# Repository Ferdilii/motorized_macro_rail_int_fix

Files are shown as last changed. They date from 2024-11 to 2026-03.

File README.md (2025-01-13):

# Motorized Macro Rail

Macro Video (https://www.youtube.com/watch?v=2CRFKH4DlHQ)

Instructables Link is [here](https://www.instructables.com/DIY-Motorized-Macro-Rail/)

This is a project for a motorized macro focusing rail.  It is used with special
"stacking" software to increase the depth of field of macro images.  This
project is presented as a modification to an existing commercial rail, but could
be extended to use a custom built rail (using steel rods and linear
bearings commonly used in at-home 3D printers and CNC mahines).

## Background

Taking images of very small objects is known as [macro
photography](https://en.wikipedia.org/wiki/Macro_photography).  Using a
[specialized
lens](https://www.bhphotovideo.com/c/product/1399604-REG/venus_optics_ve2528sfe_laowa_25mm_f_2_8_2_5_5x.html),
or an [attachable
modifier](https://www.bhphotovideo.com/c/product/275182-REG/Raynox_DCR_250_DCR_250_2_5x_Super_Macro.html)
makes this type of photography possible.

Due to the [physics of photographic lenses](https://en.wikipedia.org/wiki/Depth_of_field), taking photos of very
small objects typically has a very low depth of field, where only a thin plane
of the object appears in focus, often much less than 1mm.

In general photography, it is possible to "stop down" the aperture to increase
the depth of field.  That is true in macro photography as well, but even stopping
down often does not sufficiently address the depth of field problem.

A modern solution is to take many photos where the focus point is slightly
shifted, then combine these using software.  For example, we would take these
photos:

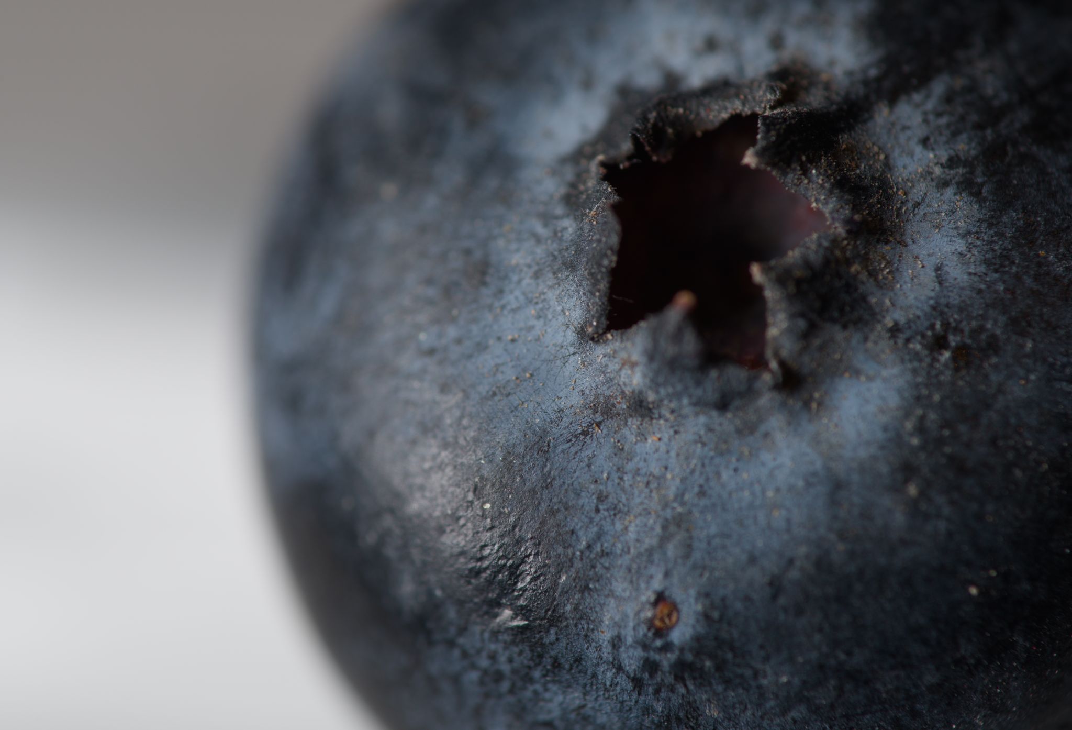
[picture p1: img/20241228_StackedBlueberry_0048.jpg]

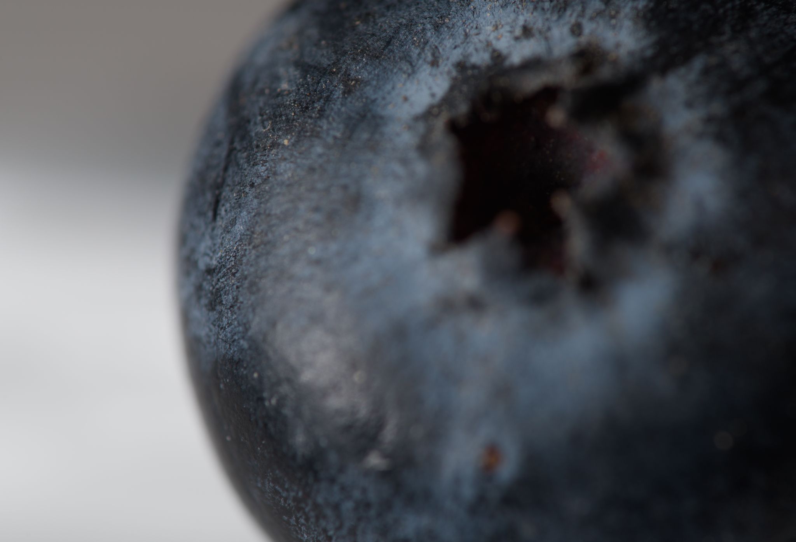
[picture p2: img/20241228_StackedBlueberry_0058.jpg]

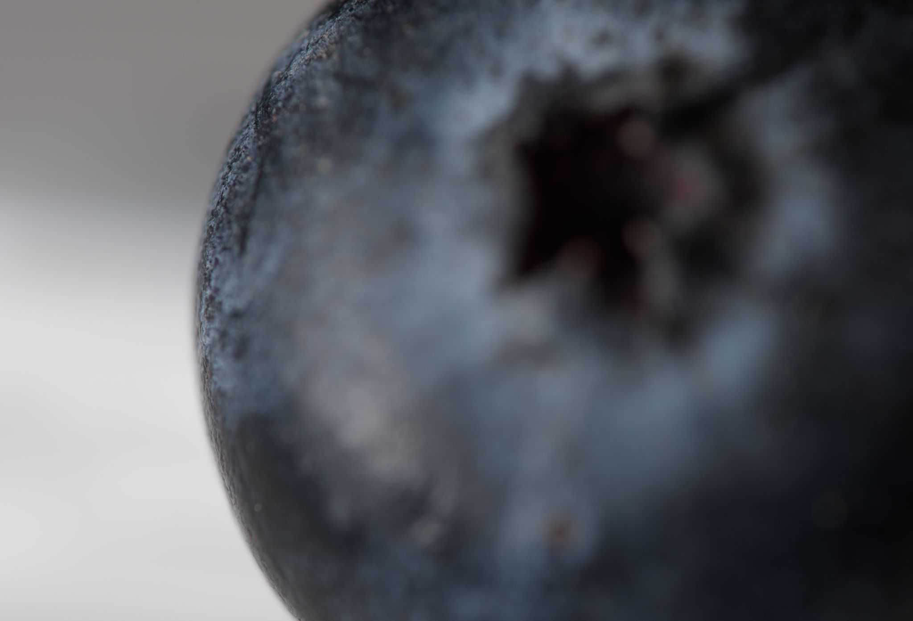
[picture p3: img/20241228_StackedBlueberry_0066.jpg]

(and 29 more)

and combine them into this "stacked" image:

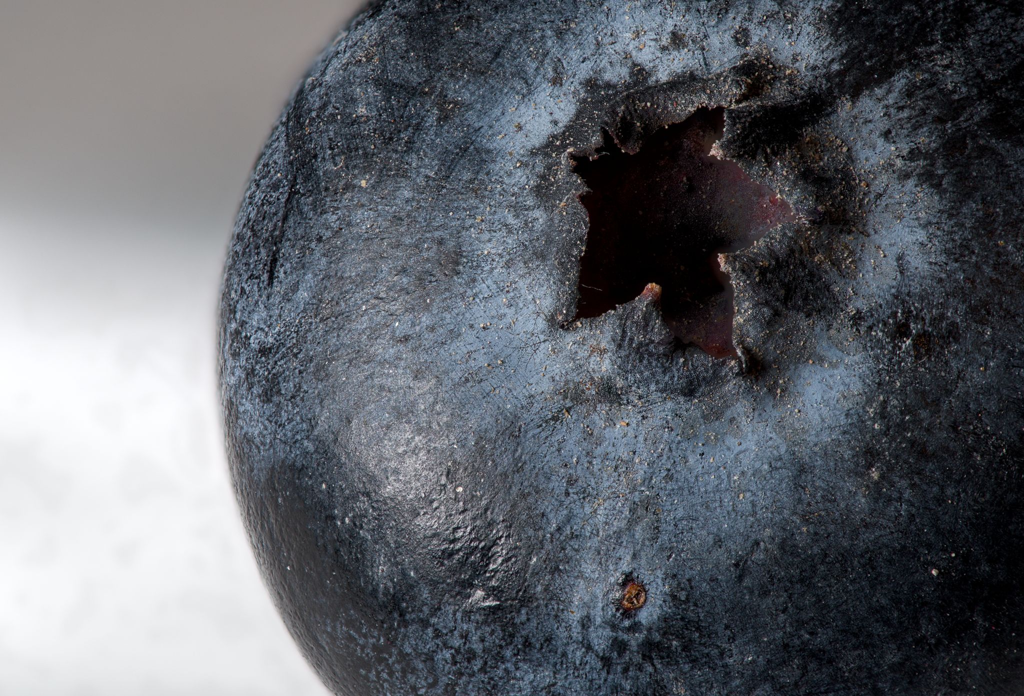
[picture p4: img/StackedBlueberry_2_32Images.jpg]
stacked image


The project here helps to take the captured photos in an automated and
consistent way.

Note that taking these photos requires either a specialized lens, an attachable lens
filter or an extension tube.  There are endless resources on the web on
gettings started.  Here is [one for the basics](https://digital-photography-school.com/macro-photography-for-beginners-part-1/).
Here is one for [extreme macro](https://ferdychristant.com/my-journey-into-extreme-macro-8ddef548e9f3), which is where a rail comes into play.
The amount of detail in this article is impressive and seems beyond what you'll
need to know to start experimenting, but a useful reference as you progress.

## Alternatives

### Manual Approaches

* You can use manual focus on your lens to vary the focus distance. That said,
it can be challenging to get the step size correct and consistent (especially on a
lens not designed primarily for manual focus).  The final stacked image will
thus often have "blurry" areas where there was no in-focus source image to use.
There is also the risk of moving the camera every time you touch it.  Still,
this can be a great way to start and get famiiar with the process.  This method
also does not limit you to small objects as stacking larger scenes can be useful
too.
* You can buy a manual focus rail at many different qualities and price points.
That is the starting point for this project.  The nice thing about these rails
is that they are easy to pack up for field work.  The downside is
that using them manually can feel like tedious work and you risk moving the
camera and introducing vibrations as you interact with the rail.

### Automated approaches

* You can buy commercial rails at different price points.  Here is
[one](https://cognisys-inc.com/stackshot-macro-rail-package.html) and
here is [another](https://www.wemacro.com/US/index.php/product/wemacro-rail-with-power-bank-cable-for-outside/).
Price aside, I think a downside of these solutions is the
interface.  One uses buttons and the other uses a phone app - both seem a bit
cumbersome compared to an analog stick when it comes to positioning the camera.
* [Some cameras](https://fujifilm-x.com/en-gb/learning-centre/using-focus-bracketing-and-stacking/)
have built in [focus stacking](https://en.wikipedia.org/wiki/Focus_stacking)
features while others support remote
control phone/computer [apps](https://camranger.com/camranger-2/) that add the
feature. A limitation here is that you will be limited to autofocus lenses and
[higher-magnification](https://www.bhphotovideo.com/c/product/1712870-REG/venus_optics_ve9028fe_laowa_90mm_f_2_8_2x.html) lenses usually do not offer autofocus as an option.

## Parts List

These are the parts and equipment I used.  Of course, any of them could be
swapped with alternatives with varying degrees of challenge depending on the
part:

### Parts

Prices are what I found in late 2024.  I am mostly suggesting
[Digikey](http://www.digikey.com) here because they let you purchase low part
counts.

* [Stepper motor](https://www.amazon.com/gp/product/B0B93L4H57) ($11) Any Nema 17 motor designed
for 3D printers will work well.  I'm using a lower power pancake style motor, which is still
sufficient for the job (as the leverage on a macro rail knob is very high)
* [Raspberry PI Pico](https://www.digikey.com/en/products/detail/raspberry-pi/SC0915/13624793) ($4).  You could
opt for the [unit with Wifi/Bluetooth](https://www.digikey.com/en/products/detail/raspberry-pi/SC0918/16608263)
if you want to try and trigger your camera wirelessly but note that this
enhancement will require firmware changes and could be a challenge.
* [128x128 OLED](https://www.amazon.com/dp/B0CFF435XZ) ($12).  The UI is 
designed for this resolution using a 8x16 font.  With some firmware changes, you
could go with a 128x64 and switch to an 8x8 font.  See
[src/firmware/README.md](src/firmware/README.md) for more details.
* [4 push-buttons](https://www.digikey.com/en/products/detail/schurter-inc/1301-9314-24/8536705) ($1).
* [Joystick](https://betafpv.com/products/literadio-transmitter-nano-gimbal-for-literadio-3-and-2-se?variant=39628763529350) ($6).
I'm using an RC gimbal (pitch-roll type) which gives a feeling of precise control.  You
an get these new or salvage one from an old RC radio.  Alternatively,
you can opt for a commonly-available ["PS2 stick"](https://www.amazon.com/HiLetgo-Controller-JoyStick-Breakout-Arduino/dp/B00P7QBGD2)
that will be less precise but possibly good-enough.
* [Voltage Regulator](https://www.digikey.com/en/products/detail/texas-instruments/LM7805CT-NOPB/3901929) ($2) most stepper
motors need a minimum of 12V, which is beyond what the PI Pico onboard regulator
can accept as input, thus you'll need a regulator to help it out.  I went with the famous
[LM7805](https://www.digikey.com/en/products/detail/texas-instruments/LM7805CT-NOPB/3901929) which will be powering the Pico
and OLED.  Anything between 3.3V and 5V which can deliver > 200 mA should be well
into the sufficiency range.
* [A4988 Stepper Motor Driver](https://www.amazon.com/HiLetgo-Stepstick-Stepper-Printer-Compatible/dp/B07BND65C8) ($2).
A Pico microcontroller is not designed to power a motor directly and you will need
power electronics.  The [A4988](https://www.pololu.com/file/0j450/a4988_dmos_microstepping_driver_with_translator.pdf)
gives you both the power and an easy-to-use interface which make the motor run smooth and quiet (using microstepping) and provides a number of protections (such as overcurrent protection).
* [Power connector](https://www.amazon.com/dp/B09128LHGG) ($2).
I'm going with a XT-60 connector used with RC LIPO batteries but it's really up to you.  The design will
support between 12V and around 30V but you'll want to double check the limits
of your chosen motor and voltage regulators.
* [Camera remote shutter release](https://www.digikey.com/en/products/detail/same-sky-formerly-cui-devices/SJ1-2503A/738680) ($1).  I went with
a 2.5mm jack for this but since it's the not the camera side, your options
are flexible.  Many cameras support a simple electronic shutter release.  If yours
doesn't, you can probably improvise something or go with the manual shutter
release option the firmware provides (more on that later).
* [4N25 Optocoupler](https://www.digikey.com/en/products/detail/liteon/4N25/385762) (< $1)
This is used to trigger the camera.  An [optocoupler](https://en.wikipedia.org/wiki/Opto-isolator) triggers the camera using light,
meaning that the electrical system of the camera and focus rail are fully isolated.  This electrical
isolation can bring some peace-of-mind about connecting your camera.
* [100 Ohm resistor](https://www.digikey.com/en/products/detail/vishay-dale/RLR07C1000GSB14/3141196) (<$1)
The optocoupler needs one of these.
* [470 uF capacitor](https://www.digikey.com/en/products/detail/rubycon/6-3YXJ470M6-3X11/3134408) (<$1)
The a4988 motor driver requests one of these on the motor voltage input to smooth
out voltage transisents that are common with powering motors.
* [2x 10 uF capacitor](https://www.digikey.com/en/products/detail/tdk-corporation/FK28X5R0J106MR000/2815522) (<$1) These help smooth the 5V power supply.

You will also need a rail.  I went with the [NM-200s](https://www.amazon.com/dp/B0BXKFGLF3?th=1)
which I acquired on sale for $150.  I'd say the [NM-180s](https://www.amazon.com/dp/B08BCCFQC3)
is likely as good for $130 retail.  There are also a number of cheaper options that I have no
direct experience with, such as [this one for $89](https://www.amazon.com/Adjustment-Photography-360%C2%B0Rotating-Compatibility-MS18/dp/B0C89CLJ8N).  If you go with a NM-XX0s rail as I used, you can use the provided `.STL` files directly.  For other rails
you will need to resize the adapter using the free OpenSCAD and instructions provided later
in this document.

### Equipment

* 3D printer.  This is used to create the motor-to-rail interface and
the housing for the electronics.  There are many techniques with wood working,
metalworking, [CNC](https://www.sainsmart.com/products/sainsmart-genmitsu-cnc-router-3018-pro-diy-kit),
etc, that could be alternatively used if you have the needed skills and equipment.
* Camera gear.  More on that in the process walkthrough later.  In short, just about
any camera with interchangeable lenses can be used. 

## Electronics Build

Here is the schematic.

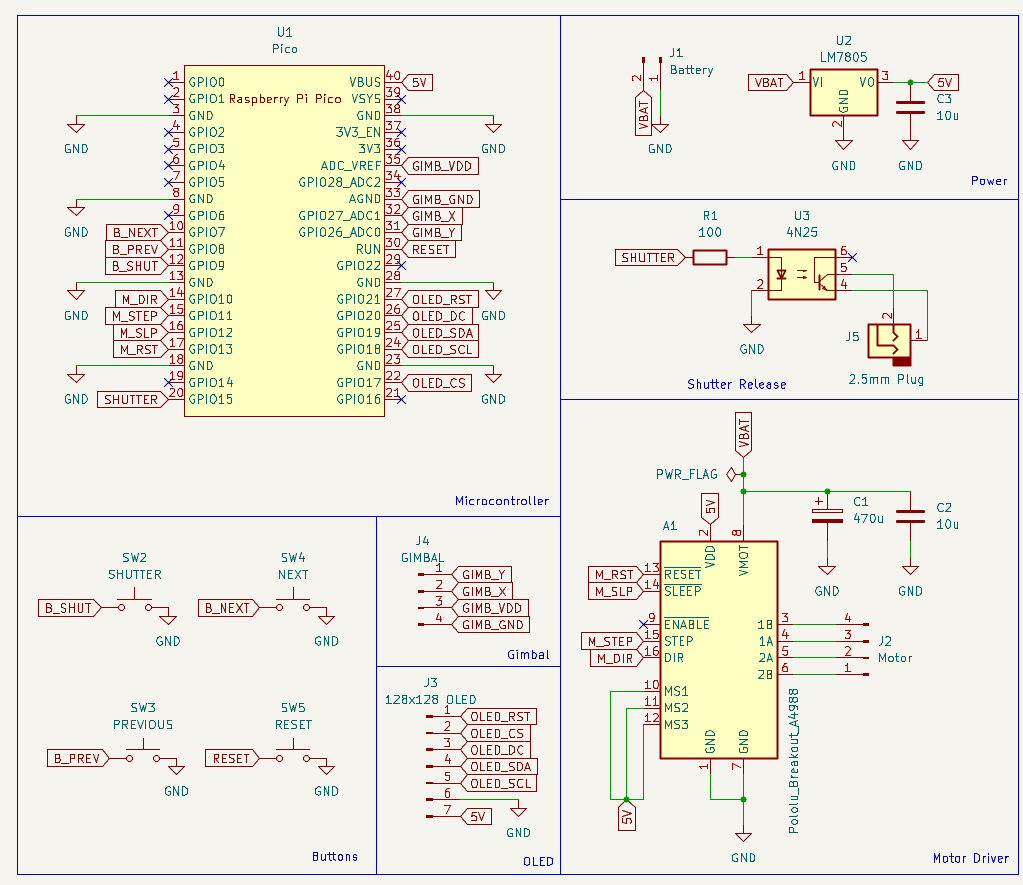
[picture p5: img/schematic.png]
schematic


There are around 2 dozen connections to be made here which makes most
assembly methods possible.  Here is the whole thing implemented on
a breadboard:

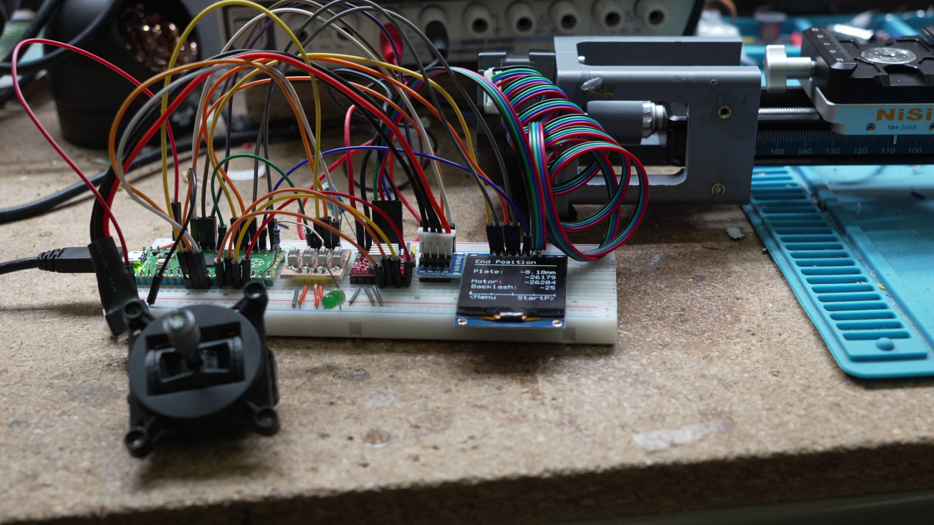
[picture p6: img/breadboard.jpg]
breadboard


You could transfer the electronics to a [perf board]() and be done
with this step.  

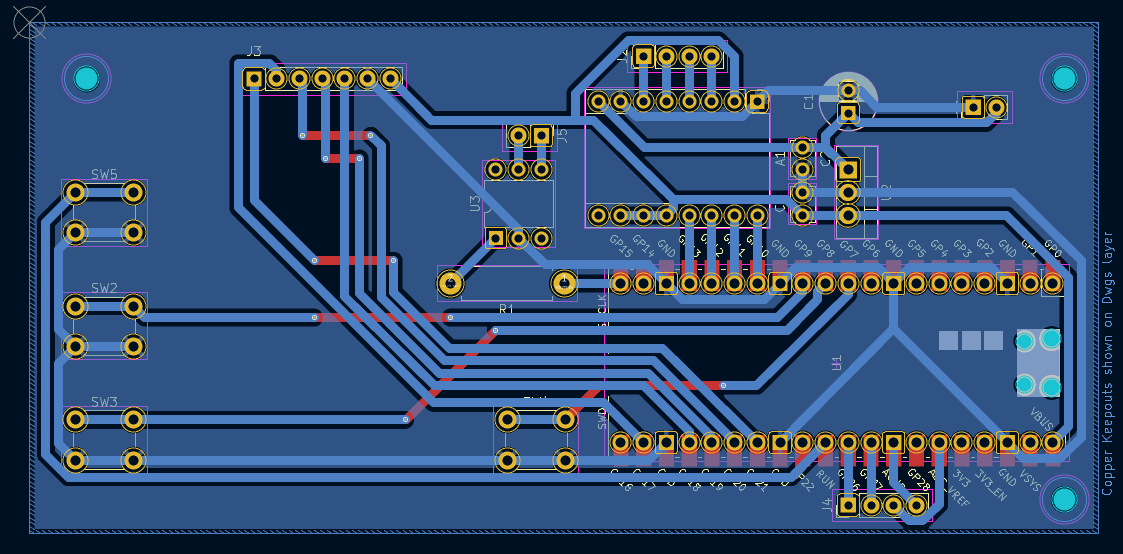
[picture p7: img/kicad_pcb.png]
pcb layout


Since I have a 3018 CNC machine, I decided to go a little farther and cut out a PCB:

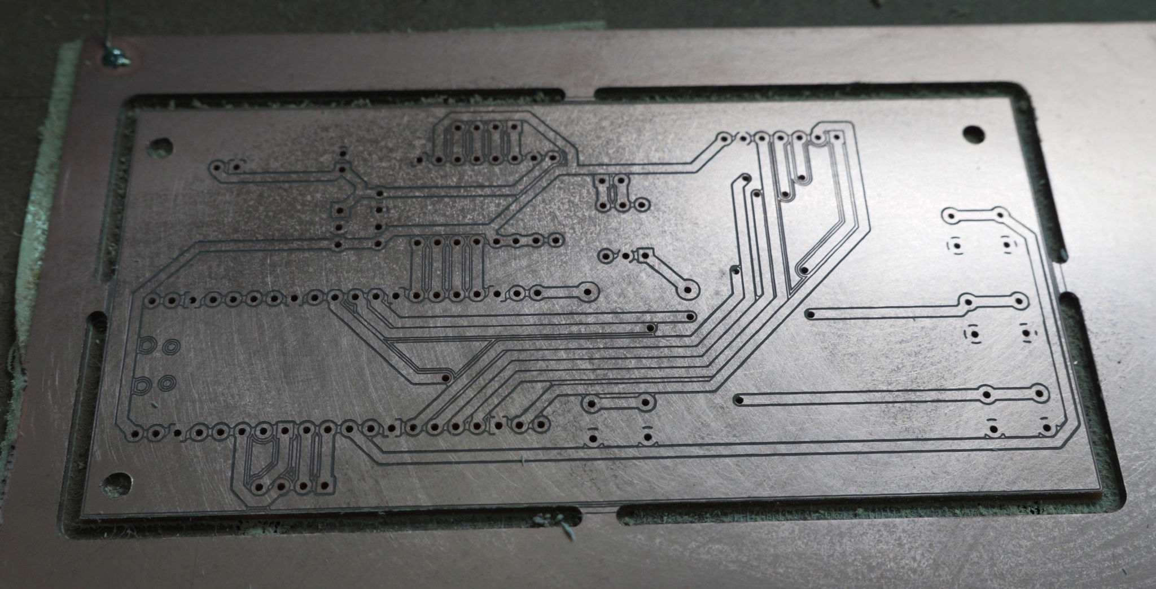
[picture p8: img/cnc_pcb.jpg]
cnc photo


Here is the board flipped over and populated with components:

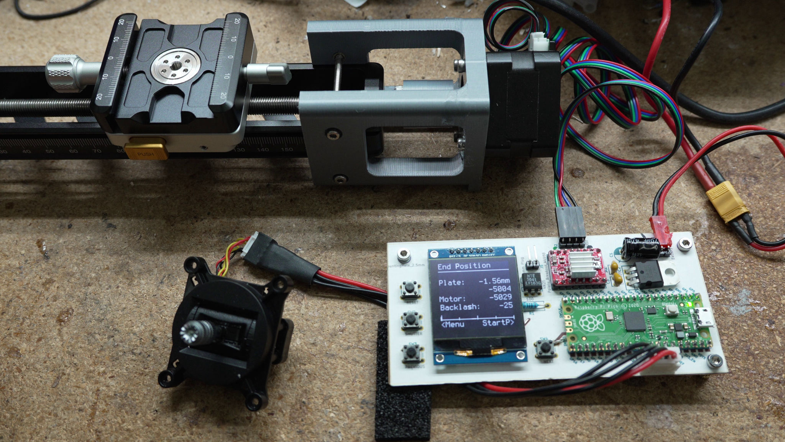
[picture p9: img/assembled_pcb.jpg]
finished board


If you want to use a CNC, chemical etch, or order a manufactured board,
you can find the needed files in the [`motor_rail_kicad/`](motor_rail_kicad) directory.

## Code Build

Here you have the "easy" option of uploading a precompiled `.uf2` file to your
Pico or the "flexible" option of building the binary yourself.  Both options are
free.

### Precompiled

There are many guides for how to do this, just a Google search away. Here is my
version.

* While holding down the `BOOTSEL` button, plug in the Pico via USB
* It should mount as a USB drive
* Copy the [`firmware/macro_rail_automater.uf2`](firmware/macro_rail_automater.uf2) file to the USB drive
* Unplug and replug the Pico

There are alternatives you can explore as well:

* There is a [`picotool`](https://github.com/raspberrypi/picotool) program which
allows you to load the `macro_rail_automater.uf2` file directly.  I prefer it.
* [Pin 30 on the Pico](https://www.raspberrypi.com/documentation/microcontrollers/pico-series.html#pinout-and-design-files) is named `RUN`.  If you drive it to 0V, it will reset the PICO.
If you do this while holding `BOOTSEL`, you can upload firmware which is
ergonomically easier and with less USB port wear-and-tear.  I
put a switch between `RUN` and ground (battery negative) whenever I go with a
Pico for this reason (as is done in the schematic above).

### Build firmware yourself

To start, you'll need a working development environment.  I'll point you to the
[official docs](https://datasheets.raspberrypi.com/pico/getting-started-with-pico.pdf) if you are not there yet.  I personally prefer following Appendix C "Manually configure your environment" first over the VS Code docs, then add VS Code later so I have both options available.

Once your blinking light project is working, you are nearly done.  Here
are the command line instructions (use the official Pico docs as a guide for VS Code)

* First, go into the [`src/`](src) directory.
* In Linux, type [`./bootstrap.sh`](src/bootstrap.sh).  In Windows, you'll need to follow
the steps listed in `./bootstrap.sh` which are identical to the official
docs.
* `cd build`
* `make`

At this point, you'll hopefully have your own `macro_rail_automater.uf2` file that you can load
on the your Pico.

## Macro Rail Physical Interface

The goal is to interface the stepper motor with the macro rail of your
choosing.  I ended up going with the [NM-200s](https://www.amazon.com/dp/B0BXKFGLF3)
focusing rail which I find sufficient but not amazing.  It has some flex which
leads to some shifts between photos but the stacking software compensates for this.
I *might* try a cheaper one or potentially DIY one with some steel rods and
linear bearings, if I find the time/motivation.

For the route I took, only two printed parts are needed.  One interfaces
the rail to the motor using a clamping interface:

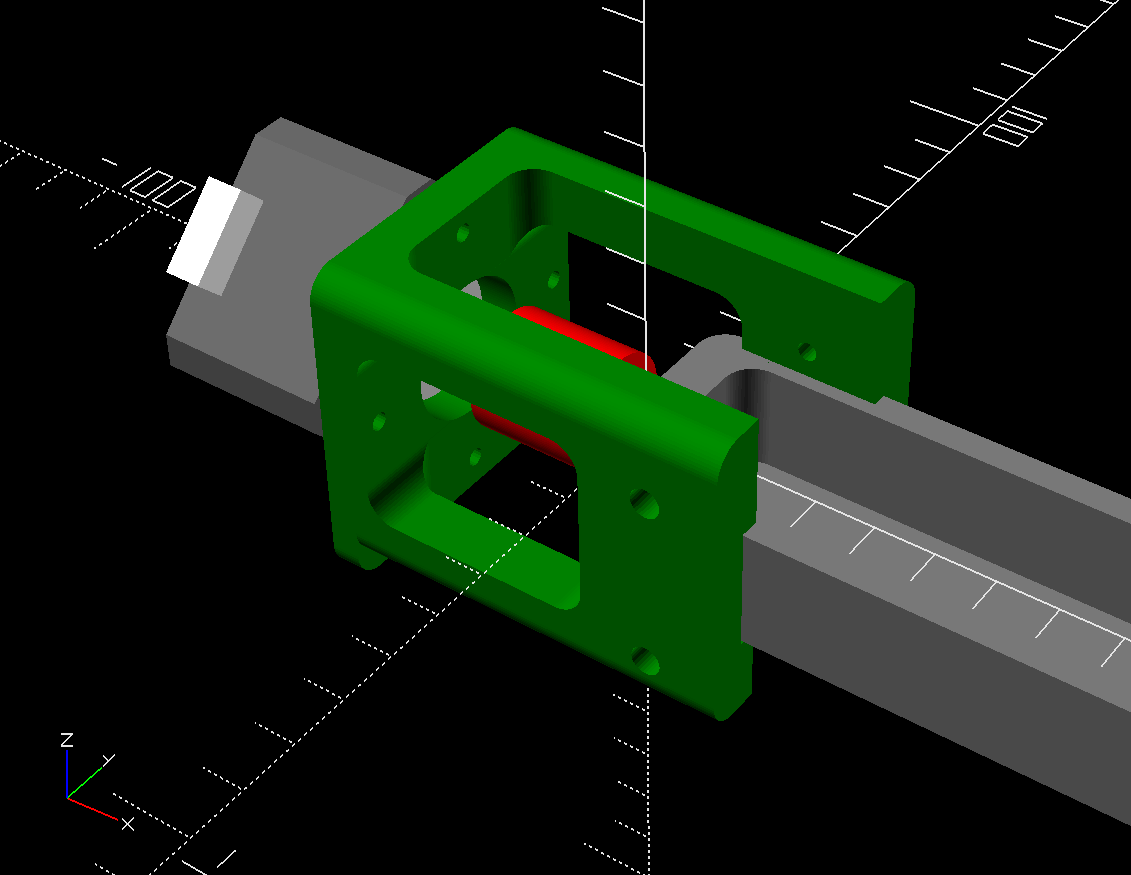
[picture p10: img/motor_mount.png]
clamp interface


The other printed part interfaces the motor shaft to the finger adjustment
knob:

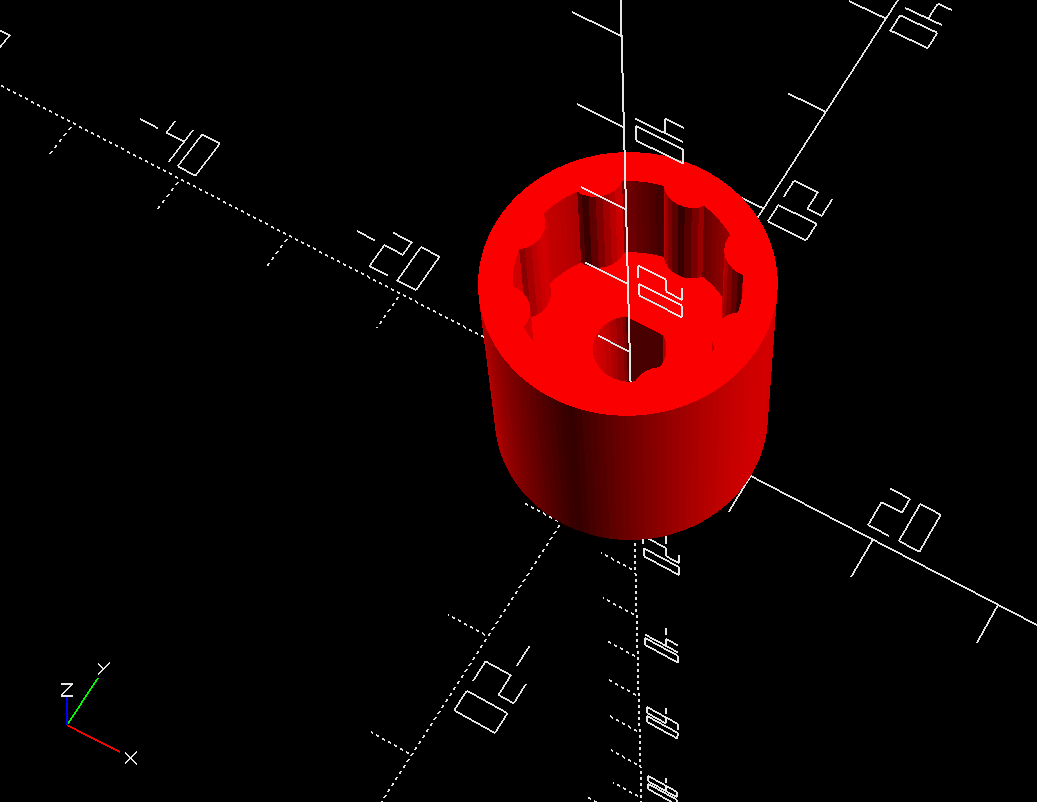
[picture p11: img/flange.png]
shaft interface


I have included rendered `.stl` files in the [3d_models/stl](3d_models/stl)
directory that you make be able to use directly if you have a compatible rail.

If you do not have a a matching rail, you can probably make a few tweaks to the
model and have a working result.  By using the freely-available [OpenSCAD](https://openscad.org/), you can adapt
the clamp interface to various different rails by editing
[`motor_mount/focus_rail.scad`](3d_models/motor_mount/focus_rail.scad) and changing
the following parameters to match your rail:

```
RAIL_BODY_WIDTH = 37.8;
RAIL_BODY_HEIGHT = 20;
```

The numbers above (in mm) are for the [NM-200s](https://www.amazon.com/dp/B0BXKFGLF3).

The knob interface design should be adaptable to most (but not all) rail
designs.  The file to change is [`motor_mount/knob.scad`](3d_models/motor_mount/knob.scad)
with the following variables likely being relevant:

```
KNOB_DIAMETER = 15.1;
KNOB_INSET_DIAMETER = 13.2;
...
finger_cutout_diameter = 4;
finger_cutout_count = 8;
```

## Motor Current Calibration

You will need to calibrate your A4988 driver board to set the current properly
for your chosen stepper motor.  Intructions on how to calibrate are
[here](https://www.pololu.com/product/1182) with alternate instructions
[here](https://ardufocus.com/howto/a4988-motor-current-tuning/).

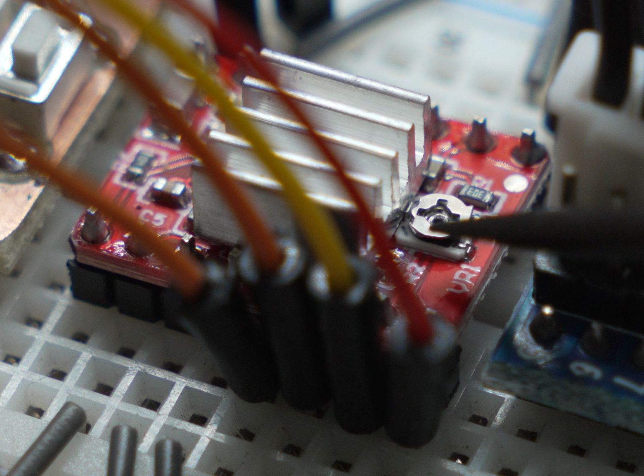
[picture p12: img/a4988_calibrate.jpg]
motor calibrate


## Firmware Settings

If you power on the unit and press the "previous button", you are taken to
a menu that lets you chang the following settings:

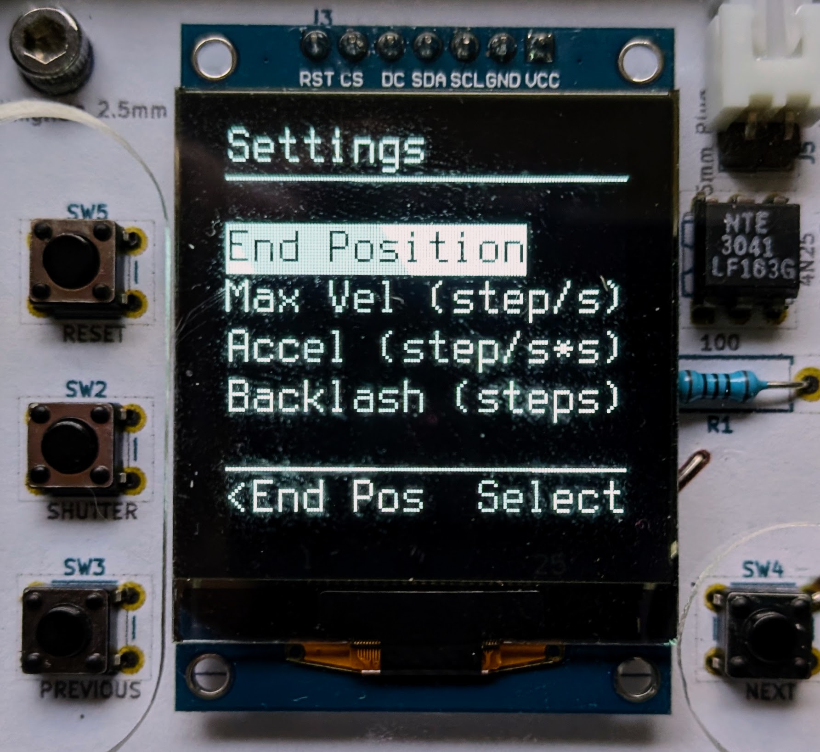
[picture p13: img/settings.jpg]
settings


* Max Velocity: The maximum motor turn speed.  Too high of a value may cause the
stepper motor to miss steps or lead to long spin down times if acceleration
is not risen to match.
* Acceletaion: The maximum motor acceleration/decelleration.  Too high of a
a value may cause the motor to miss steps or lead to rail vibrations.
* Backlash: When the motor switches direction, it will take some slack before
the main gear is engaged, this is known as backlash.  If you want a perfect
value, you can run the test mode with a caliper attached to the rail.
It's usually not critical that this number be fully tuned.
* Settle Seconds: This is how long the controller should wait between
stopping the rail and taking a photo.  The intent is to allow any
vibrations/oscillations from rail decelleration to subside.  You
can also use this value to give your camera more time to write to
its memory card.

### Steps / mm

This final menu item relates to both your motors steps/rotation and
your rails rotations/mm.  The a4988 driver is configured in the schematic
above to 16x microstep mode, meaning that 16 steps equal one step on the motor.
The formula to use is thus:

```
  motor_steps_per_rotation * 16 / mm_per_rotation
```

For my case,
I'm personally using a
[200 steps/rotation stepper motor](https://www.amazon.com/gp/product/B0B93L4H57) and a 
[1 rotation/mm rail](https://www.amazon.com/dp/B0BXKFGLF3),
thus my number will be 200 * 16 / 1 = 3200.

## Controller Case

In the folder [3d_models/controller](3d_models/controller/), there is a file named [controller.scad](3d_models/controller/controller.scad), which OpenSCAD will render like this:

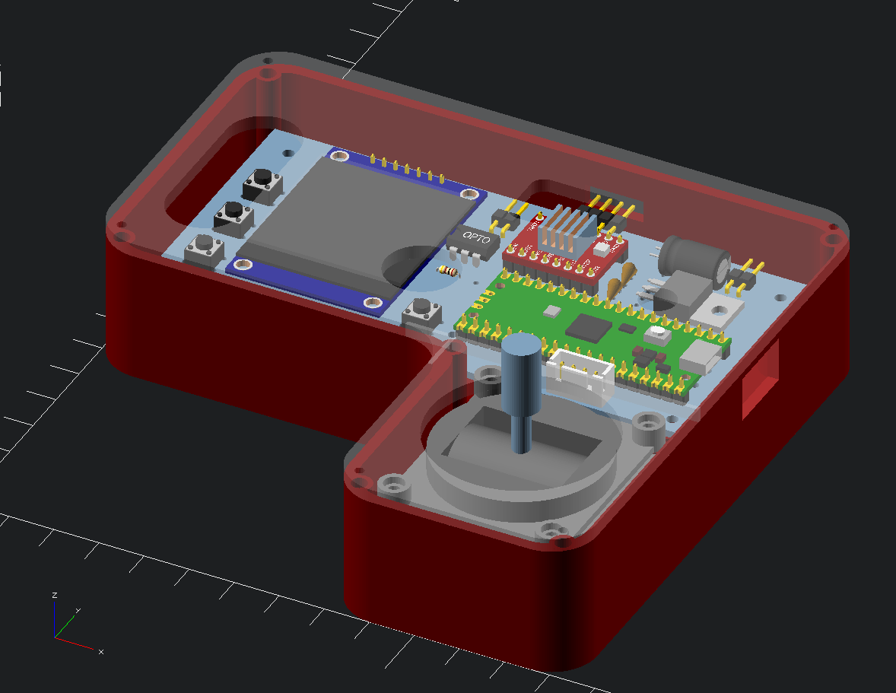
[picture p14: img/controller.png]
controller image


This model is intended for the parts and PCB model that I'm using.  If you went
with different parts, made a differently-shaped PCB, or do not have a CNC
machine for the acrylic cover, you can either try to modify the given design or
make a custom one using whatever parts / methods work for you.

If you want to start with an STL file, you can find one at [3d_models/stl/controller.stl](3d_models/stl/controller.stl)

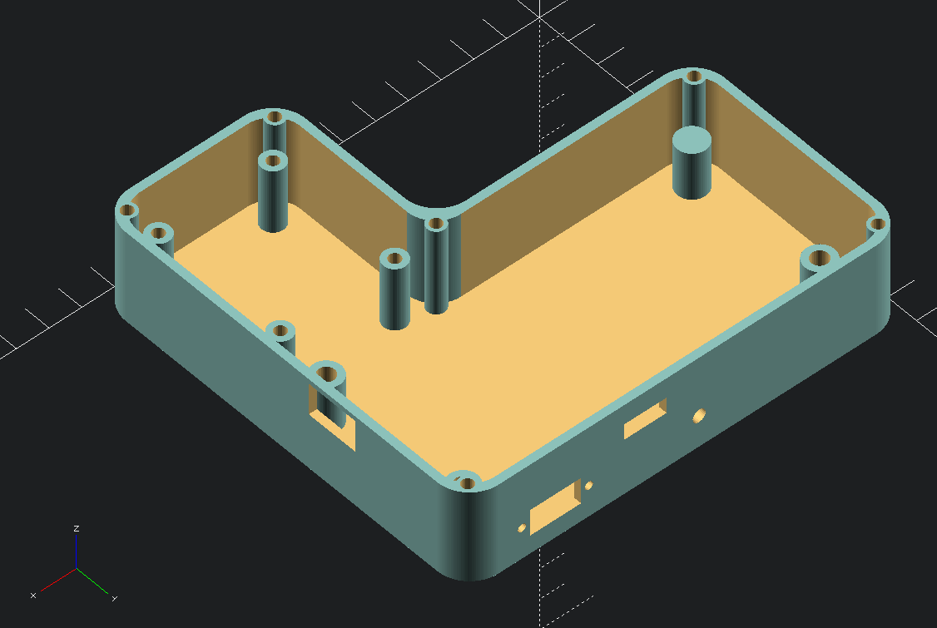
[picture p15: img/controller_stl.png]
controller stl


If you want to edit the OpenSCAD model directly, it can be found at
[3d_models/controller/controller.scad](3d_models/controller/controller.scad).
The model is parametric and has many varialbes you can change and experiement
with.  The bottom of the file allows you to turn components on and off using th the usual OpenSCAD prefixes of `*`, `!` and `//`:

```
// comment out everything but controller for the 3d print model
controller(false);
placed_pcb();
placed_gimbal(); 
cover();
// comment out everything but this to create a dxf projection
//cover_projection();
```

The `cover_projection()` can be used to create a `.dxf` export for CNC or a laser cut.
Alterrnatively, you can 3D print the cover, likely with some modifications
to allow the screen to be viewed:

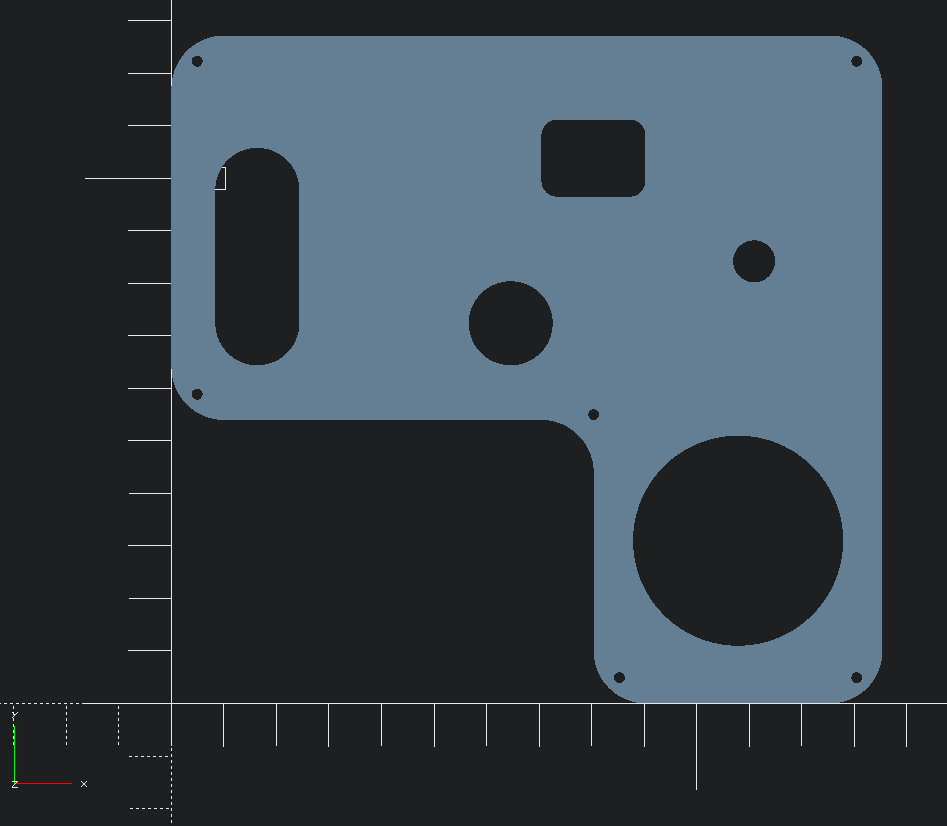
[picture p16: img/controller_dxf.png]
controller dxf


An exported DXF is available at [3d_models/dxf/controller_cover.dxf](3d_models/dxf/controller_cover.dxf) if you would like to use that as your starting point.

## Process Walkthrough

This section talks about the end-to-end experience of using the rail.

### Setup

You first need to attach the stepper motor to the rail by sliding it on and
*gently* tightening the bolts (don't overdo it).  The motor can easily be
detached if you don't need it for a given session.`

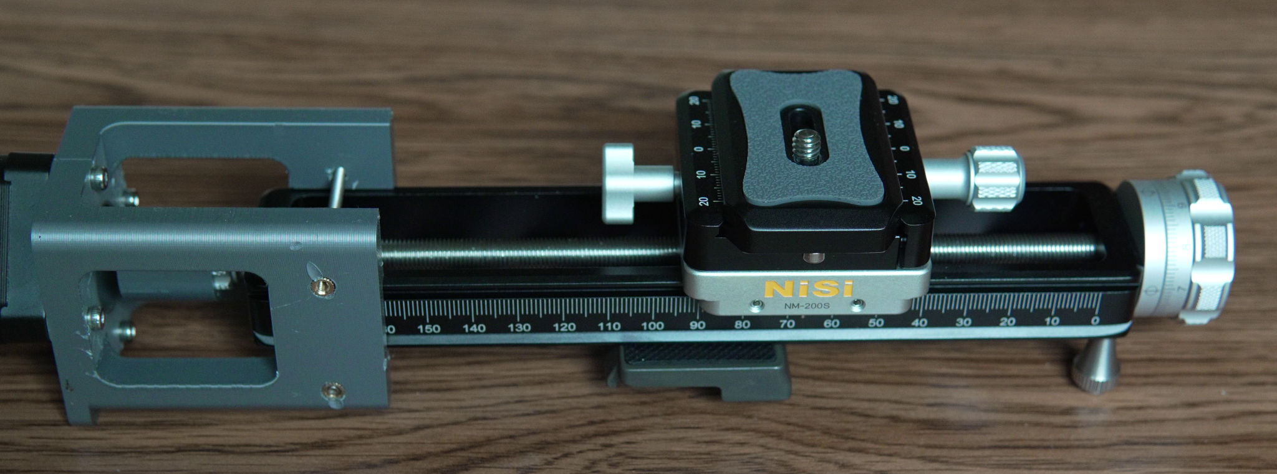
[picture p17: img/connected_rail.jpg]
attach rail


Next line up the camera and target and make sure that nothing is moving.

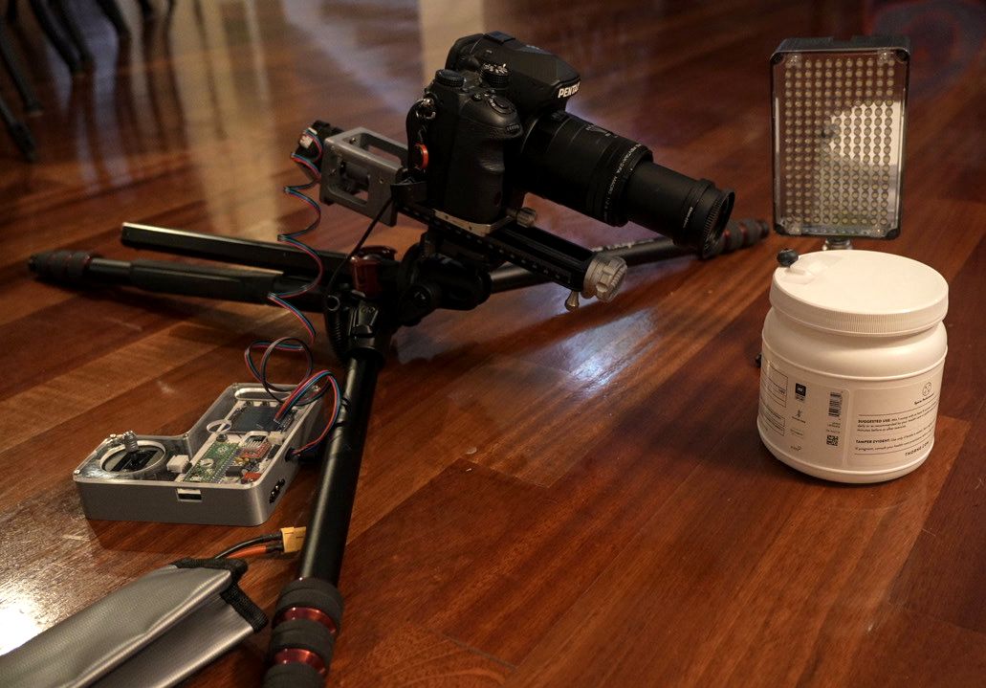
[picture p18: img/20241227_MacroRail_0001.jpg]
camera setup


It's good to have a light on your subject to reduce to exposure time and make
the light consistent.  Where you place the light is an artistic choice but side
lighting is a good starting point.  Flash is an option but you might need to
slow down your process to allow the flash to charge between shots.

You'll want manual everything on your camera, focus, shutter speed, aperture,
ISO and white balance.  If these parameters change in any of the photos,
it can create problems with the stacking software.

I suggest f/5.6, f/8 or f/11 for aperture.  Wider apertures will have (possibly
not perceptible) sharpness improvements due to less diffraction but you
will need to take more images to due to less depth of field.

### Find most distant point

Power on the focusing rail and use the joystick to find the farthest out point
(note you can also find the closest point first, if you prefer).

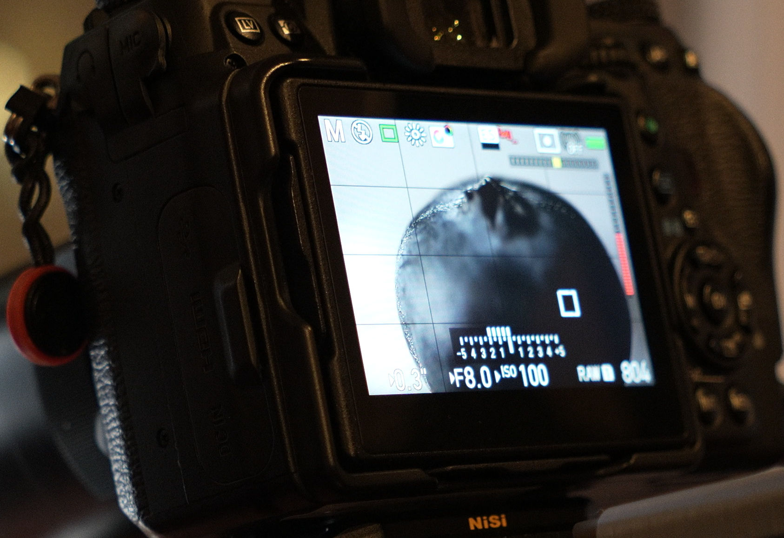
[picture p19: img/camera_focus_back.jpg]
back of camera


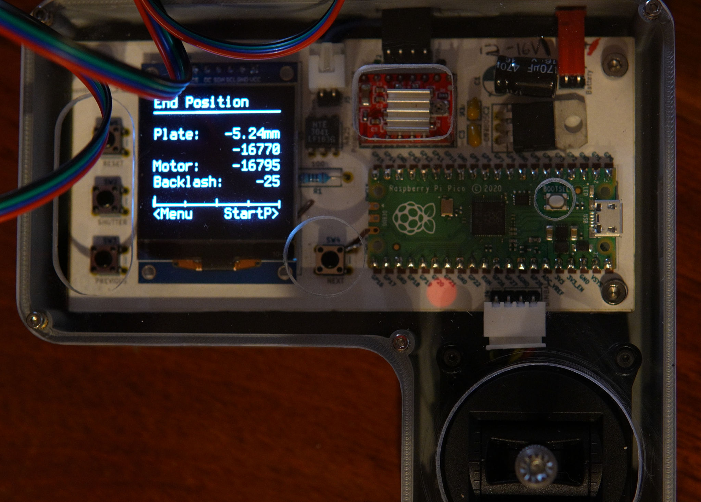
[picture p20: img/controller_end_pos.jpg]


### Find closest point

Hit the 'next' button and find the closest point.

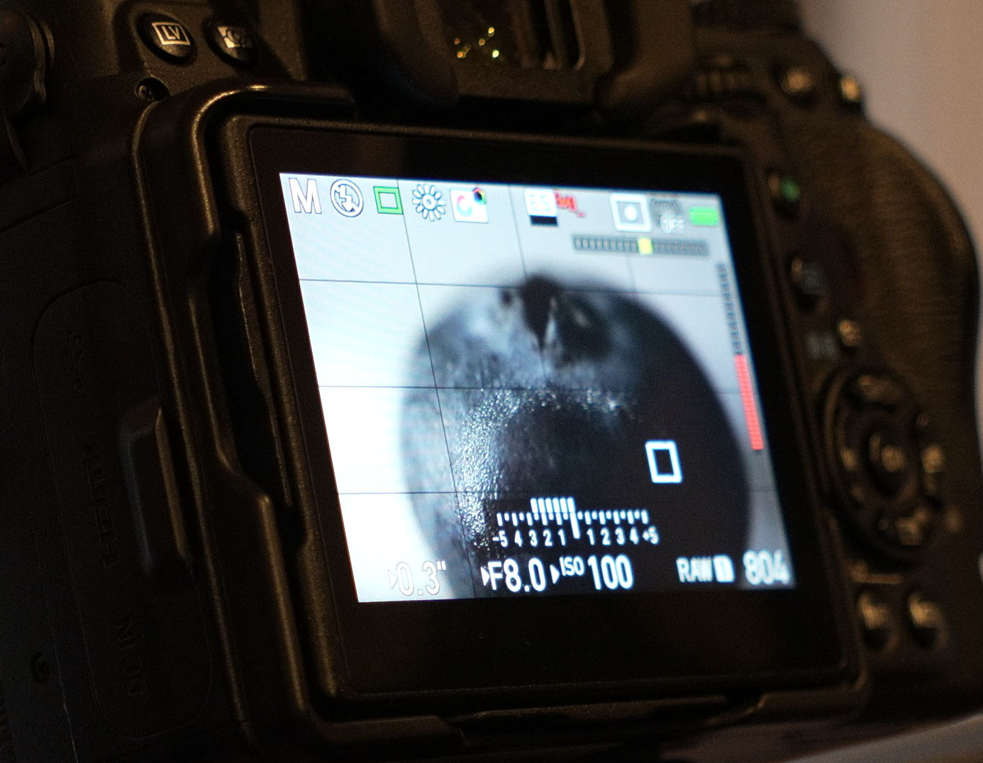
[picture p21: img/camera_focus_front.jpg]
front of camera


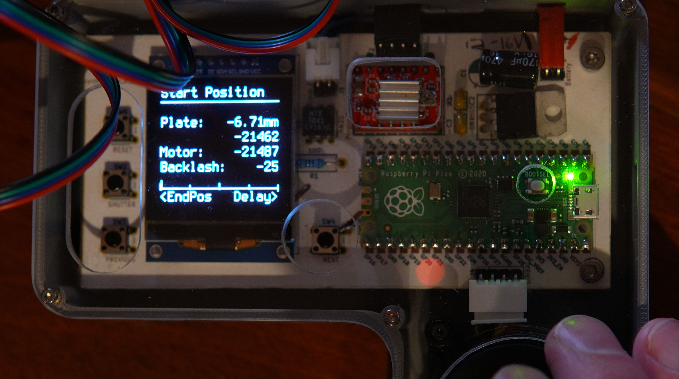
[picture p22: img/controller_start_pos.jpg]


### Choose shot delay

Hit the 'next' button to choose the shot delay. My exposure settings indicate
that a photo will take 1/8th of a second to take.  You also want to think about how
long the camera will take to write the photo to the SD card (most cameras will buffer
shots in memory, but maybe not enough).  If your camera offers a setting for
["electronic shutter"](https://photographylife.com/mechanical-electronic-shutter-efcs),
I suggest turning it on as any amount of
[shutter shock](https://photographylife.com/shutter-shock) is especially
visible during macro work.

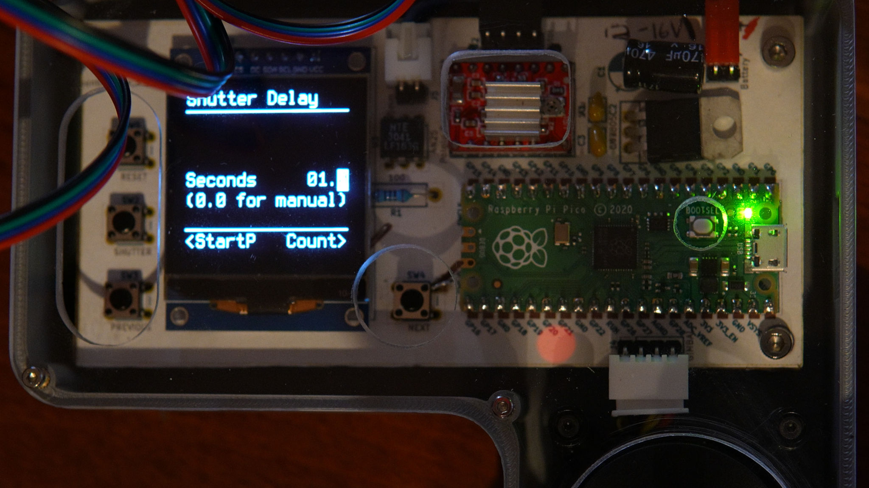
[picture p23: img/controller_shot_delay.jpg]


If you don't have the remote shutter working with your camera, you have
the option of choosing `0.0` here.  In that case, the rail will pause
after each photo, giving you as much time as you need to manually take
the photo.  In this mode, the "next" button is used to continue.

### Choose image count

The correct image count depends on many variables:

- How magnified the subject actually is
- How many megapixels your camera has and if you plan to pixel peep
- Your choice of aperture setting

You'll need to experiment.  If you do not know where to begin, I suggest f/8
and 0.2mm and see how it goes (or try [this chart](https://www.wemacro.com/?p=529)).

Hit the 'next' button and choose your shot count

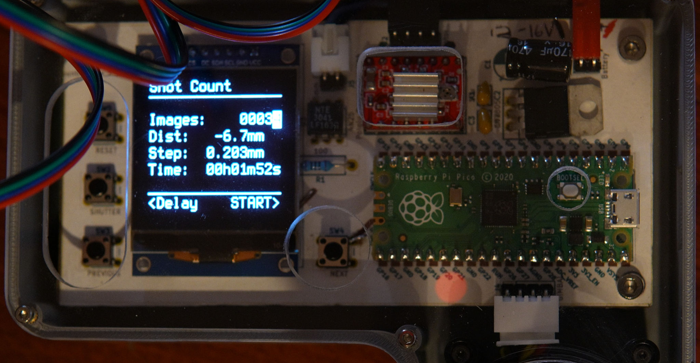
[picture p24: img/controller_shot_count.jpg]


### Take photos

Hit the `next` button to take all of the photos.  You can pause/resume the process
with the `next` button or cancel it with the `back` button.  If you find a need
to abort everything quickly or just want to start over, you can press the `reset`
button (I suggest using next/back over reset if the motor is spinning).

When all photos are taken, you have the option of repeating the process in the
reverse direction with the 'next' button or starting over with the 'back' button.

### Load onto computer and run software

I suggest Helicon focus for reasonably priced, turn key software with a free trial
period.  The software is for mac or windows but I am running it in Linux with Wine
and it runs fine.

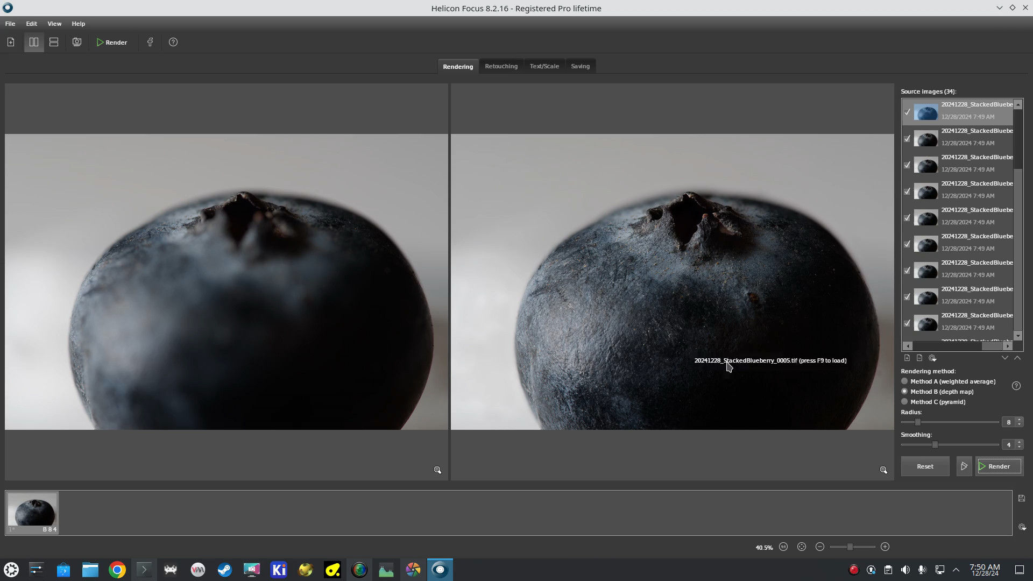
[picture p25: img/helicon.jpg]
helicon interface


If you want a free/open source solution, check out the [focus stack](https://github.com/PetteriAimonen/focus-stack)
project.  The main downside of going this route is that the excellent
post-stack retouching features of Helicon are not present, but many people
are able to use the software to produce excellent images regardless:

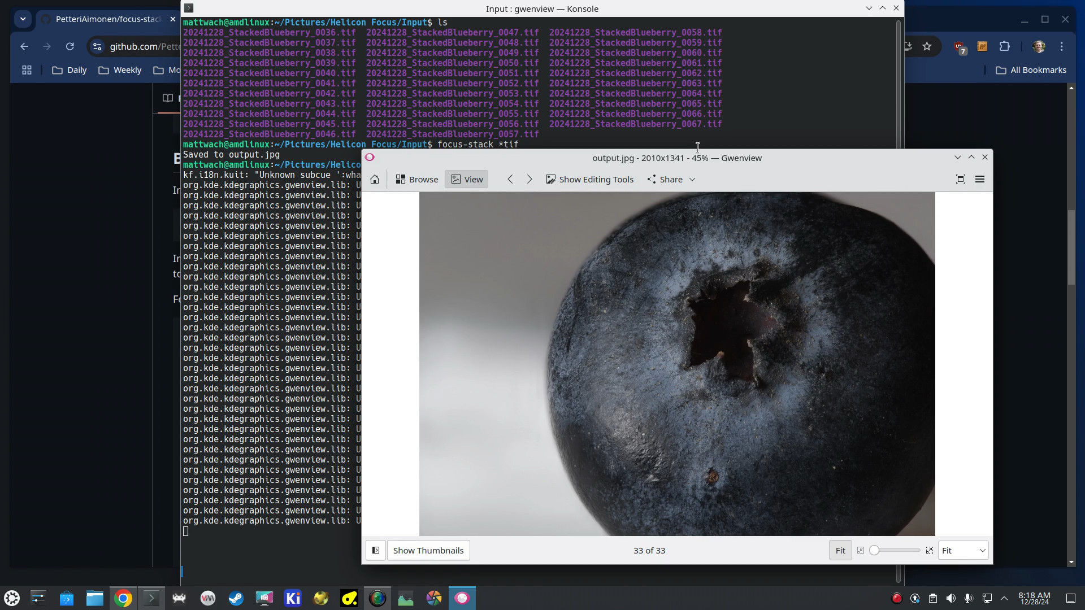
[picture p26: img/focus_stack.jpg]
focus stack interface


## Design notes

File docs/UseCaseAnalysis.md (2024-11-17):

The purpose of this doc is to help design the user interface, especially in
terms of streamlining the primary usecase.

## Primary Usecase

Bob would like a set of images for a focus stacking program.

### Step 1: Bob step up his subject, macro rail, and camera.

Bob also connects the shutter release cable from the module to the camera

### Step 2: End Point Selection

Bob can freely move the camera with the control stick and hit next to go to the
next step.

* From this point forward, Bob can also go back.
* Also activated is the manual shutter release button that bob can press
  at any time during setup.
* The unit helps bob with backlash management by showing a scale.  e.g.  |....|...|
* The unit shows coordinates in steps and mm.  It shows motor in steps only
  and plate position (backlash compensated) in both mm and steps.
* The control stick offers fowward and back for normal movement and side to side for
  finer tuning.

```
 |012345689012345
 +---------------+
0|End Pt Select  |
1|               |
2|Plate:  34.60mm|
3|          55360|
4|Motor:    55000|
5|               |
6|Backlash    -12|
7||      |      ||
 +---------------+
```

### Step 4: Start point selection

At the start of this step, the unit is considered "zeroed".  The positive direction
for the 1d coordinate system is distance from subject.  So if you are behind the camera
then the number is increasing when the camera is moving toward you.

Other steps are similar to end point selection

### Step 5: Shot parameters

Bob is shown something like this

```
 |012345689012345
 +---------------+
0|Parameters     |
1|               |
2|Shots:     010 |
3|Delay:   04.1s |
4|               |
5|Step:   1.01mm |
6|          1616 |
7|Time: 00:00:00 |
 +---------------+
```

### Step 6: Start

```
 |012345689012345
 +---------------+
0|               |
1|               |
2|Press Shutter  |
3|Button To      |
4|Begin          |
5|               |
6|               |
7|               |
 +---------------+
```

### Step 7: Process

Bob can press the next button to pause the process
Bob can press the shutter button to continuue
Bob can press the prev to cancel

```
 |012345689012345
 +---------------+
0|Running        |
1|               |
2|Shot:   002/010|
3|Time:  00:00:08|
4|Left:  00:01:12|
5|               |
6|[next] > pause |
7|[prev] > cancel|
 +---------------+
```

## Settings

Pressing the setting button offers a selection

```
 |012345689012345
 +---------------+
0|Settings       |
1|               |
2|Backlash       |
3|Speed          |
4|Calibrate mm   |
6|Min Step       |
7|               |
 +---------------+
```

```
 |012345689012345
 +---------------+
0|Backlash       |
1|               |
2|               |
3|Steps:    12345|
4|               |
5|               |
6|[next] > test  |
7|[prev] > back  |
 +---------------+
```

```
 |012345689012345
 +---------------+
0|Speed          |
1|               |
2|Accel:    12345|
3|Max Vel: 123455|
4|        steps/s|
5|Settle:   00.5s|
6|               |
7|[prev] > back  |
 +---------------+
```

```
 |012345689012345
 +---------------+
0|Calibrate mm   |
1|               |
2|               |
3|Steps/mm: 12345|
4|               |
5|[up/dn] > 10mm |
6|[lt/rt] > 1mm  |
7|[prev] > back  |
 +---------------+
```

```
 |012345689012345
 +---------------+
0|Min Step       |
2|            1  |
3|            2  |
4|            4  |
5|            8  |
5|           16  |
6|               |
7|[prev] > back  |
 +---------------+
```

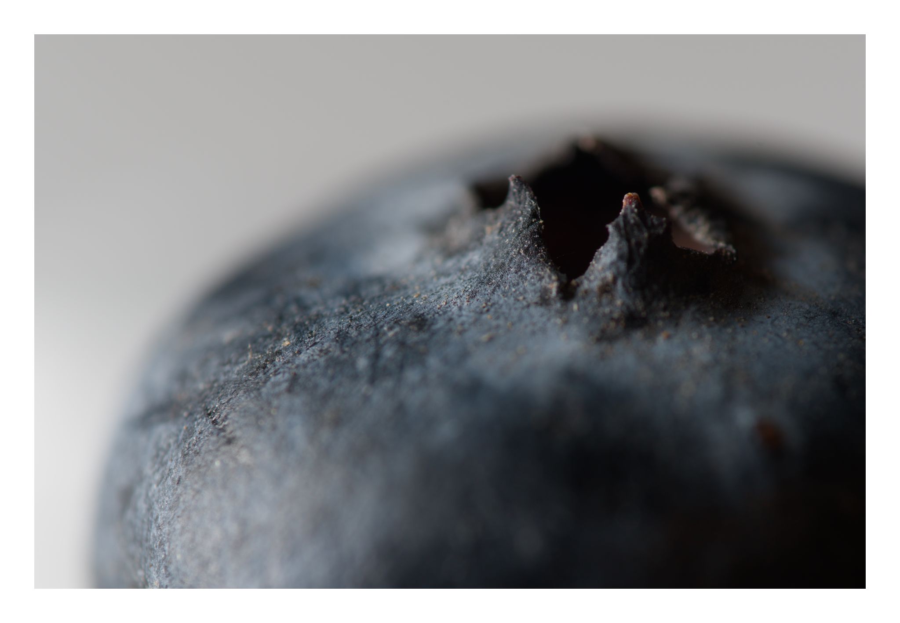
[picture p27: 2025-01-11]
img/20241228_StackedBlueberry_0022.jpg

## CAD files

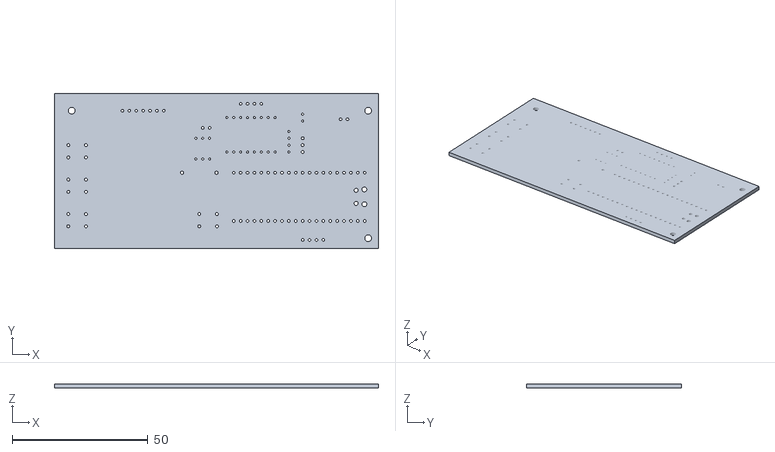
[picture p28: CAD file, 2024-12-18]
3d_models/controller/macro_rail_kicad_PCB.stl
119.4 x 57.2 x 1.60

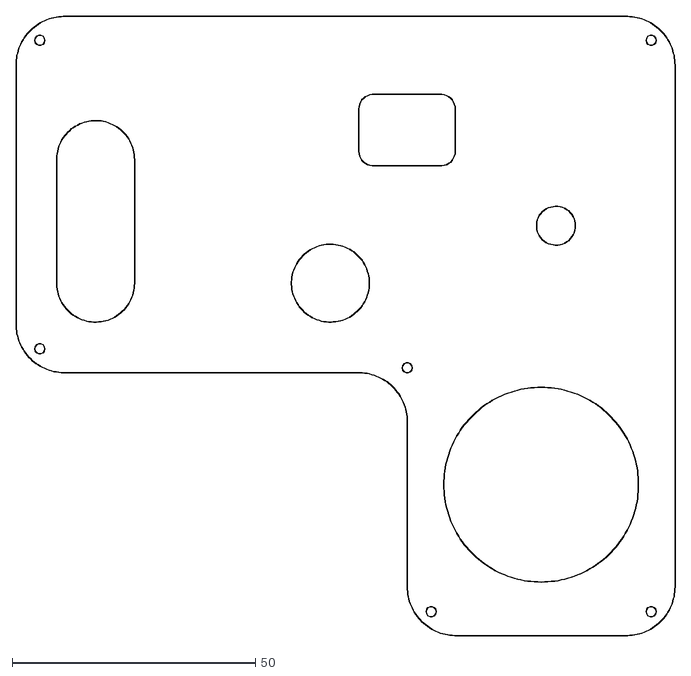
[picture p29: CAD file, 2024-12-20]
3d_models/dxf/controller_cover.dxf
135.4 x 127.2

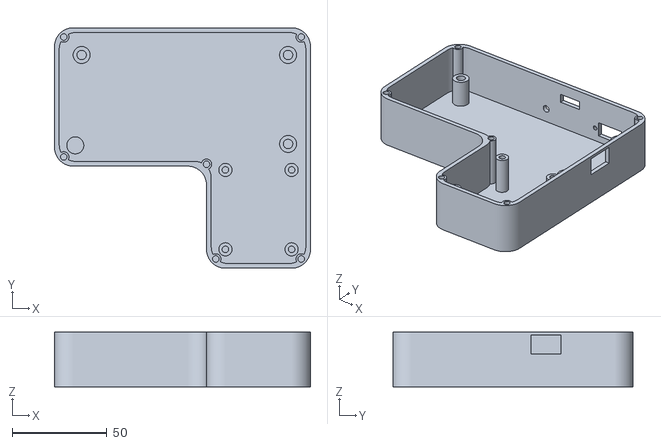
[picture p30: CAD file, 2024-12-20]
3d_models/stl/controller.stl
135.4 x 127.2 x 29.0

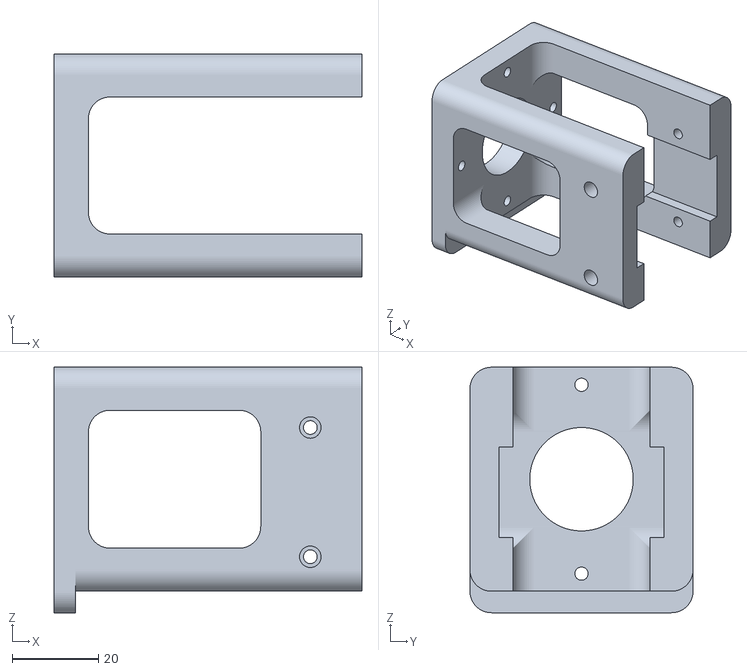
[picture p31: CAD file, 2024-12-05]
3d_models/stl/ns200_motor_mount.stl
71.5 x 51.8 x 57.0

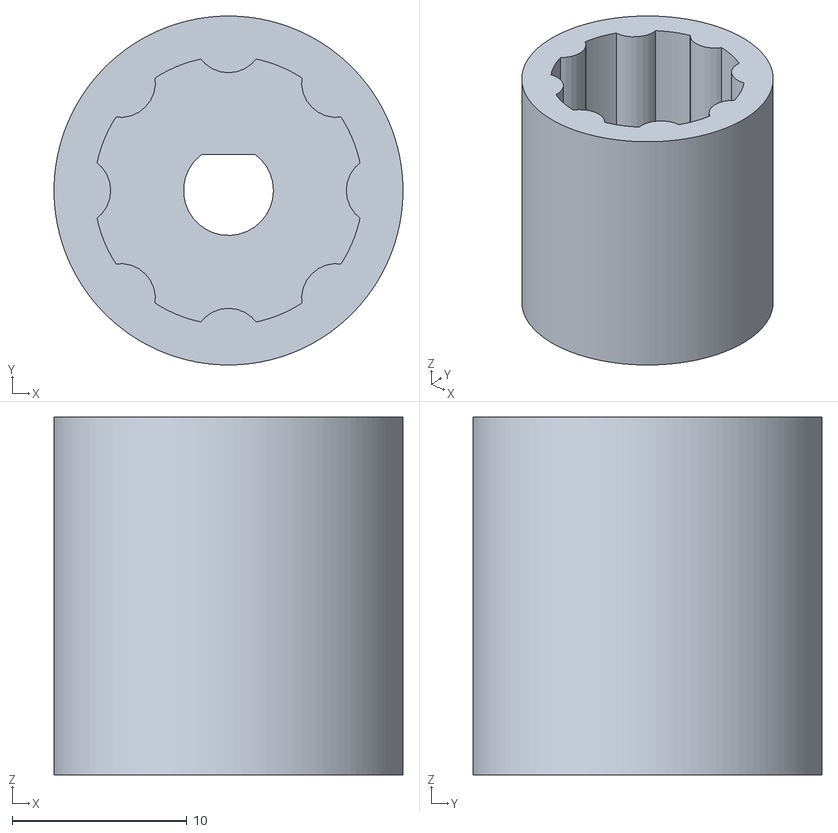
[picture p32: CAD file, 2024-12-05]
3d_models/stl/ns200_flange.stl
20.0 x 20.0 x 20.5

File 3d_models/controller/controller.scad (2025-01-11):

use <lib/mattwach/util.scad>
include <pcb.scad>
include <gimbal.scad>

pcb_x = 8;
gimbal_xpad = 10;
gimbal_ypad_top = 10;
gimbal_ypad_bottom = 10;
gimbal_y = GIMBAL_HOLE_YSPAN / 2 + gimbal_ypad_bottom;

pcb_ypad = 8;
controller_base_thickness = 2;
pcb_top_clearance = 7;
gimbal_z = controller_base_thickness + 20;
pcb_y = GIMBAL_HOLE_YSPAN + gimbal_ypad_top + gimbal_ypad_bottom;
pcb_z = controller_base_thickness + gimbal_z - pcb_top_clearance;
controller_fillet = 10;
controller_xsize = PCB_XSIZE + pcb_x * 2;
controller_ysize = PCB_YSIZE + pcb_y + pcb_ypad;
controller_zsize = pcb_z + pcb_top_clearance + 5;
gimbal_x = controller_xsize - GIMBAL_HOLE_XSPAN / 2 - gimbal_xpad;
wall_thickness = 2.5;
hole_inset = 4.9;

plate_mounting_holes = [
  [hole_inset, controller_ysize - hole_inset],
  [controller_xsize - hole_inset, controller_ysize - hole_inset],
  [hole_inset, pcb_y - pcb_ypad + hole_inset],
  [controller_xsize - GIMBAL_HOLE_XSPAN - gimbal_xpad * 2, pcb_y - pcb_ypad + 1],
  [controller_xsize - GIMBAL_HOLE_XSPAN - gimbal_xpad * 2 + hole_inset, hole_inset],
  [controller_xsize - hole_inset, hole_inset],
];

module controller_slice(inset, zsize) {
  fillet = controller_fillet - inset / 2;
  module corner() {
    cylinder(r=fillet, h=zsize);
  }

  module upper() {
    hull() {
      txy(fillet + inset, controller_ysize - fillet - inset) corner();
      txy(controller_xsize - fillet - inset,
          controller_ysize - fillet - inset) corner();
      txy(fillet + inset, pcb_y + fillet - pcb_ypad + inset) corner();
      txy(controller_xsize - 1 - inset,
          pcb_y - pcb_ypad + inset) cube([1,1,zsize]);
    }
  }

  module lower() {
    hull() {
      txy(controller_xsize - fillet - inset, fillet + inset) corner();
      txy(controller_xsize + fillet - GIMBAL_HOLE_XSPAN - gimbal_xpad * 2 + inset,
          fillet + inset) corner();
      txy(controller_xsize - GIMBAL_HOLE_XSPAN - gimbal_xpad * 2 + inset,
          pcb_y - pcb_ypad + inset) cube([
            GIMBAL_HOLE_XSPAN + gimbal_xpad * 2 - inset * 2, 1, zsize]);
    }
  }

  module inner() {
    translate([
        controller_xsize - GIMBAL_HOLE_XSPAN - gimbal_xpad * 2 - fillet + inset,
        pcb_y - pcb_ypad - fillet + inset,
        0]) difference() {
          cube([fillet + 1, fillet + 1, zsize]);
          tz(-overlap) cylinder(r=fillet, h=zsize + overlap * 2);
    }
  }

  union() {
    upper();
    lower();
    inner();
  }
}

module controller(open_view=false) {
  zsize = open_view ? 2 : controller_zsize;

  module top_plate_mounting_posts() {
    post_diameter = 5.5;
    module post() {
      cylinder(d=post_diameter, h=zsize);
    }
    for (i=[0:len(plate_mounting_holes)-1]) {
      txy(plate_mounting_holes[i][0], plate_mounting_holes[i][1]) post();
    }
  }

  module top_place_mouting_holes() {
    module hole() {
      hole_diameter = 3.5;
      hole_depth = 10;
      tz(zsize - hole_depth) cylinder(d=hole_diameter, h=hole_depth + overlap);
    }

    for (i=[0:len(plate_mounting_holes)-1]) {
      txy(plate_mounting_holes[i][0], plate_mounting_holes[i][1]) hole();
    }
  }

  module pcb_mounts() {
    post_diameter = 9;
    module post() {
      cylinder(d=post_diameter, h=pcb_z);
    }

    txy(pcb_x + 3, pcb_y + 3) post();
    txy(pcb_x + 6.35, pcb_y + 50.8) post();
    txy(pcb_x + 115.55, pcb_y + 50.8) post();
    txy(pcb_x + 115.55, pcb_y + 3.75) post();
  }

  module pcb_mount_holes() {
    module hole() {
      hole_diameter = 5;
      hole_depth = 10;
      tz(pcb_z - hole_depth) cylinder(d=hole_diameter, h=hole_depth + overlap);
    }

    txy(pcb_x + 6.35, pcb_y + 50.8) hole();
    txy(pcb_x + 115.55, pcb_y + 50.8) hole();
    txy(pcb_x + 115.55, pcb_y + 3.75) hole();
  }

  module gimbal_mounting_posts() {
    post_diameter = 7;
    module post() {
      cylinder(d=post_diameter, h=gimbal_z);
    }
    txy(gimbal_x - GIMBAL_HOLE_XSPAN / 2, gimbal_y - GIMBAL_HOLE_YSPAN / 2) post();
    txy(gimbal_x + GIMBAL_HOLE_XSPAN / 2, gimbal_y - GIMBAL_HOLE_YSPAN / 2) post();
    txy(gimbal_x - GIMBAL_HOLE_XSPAN / 2, gimbal_y + GIMBAL_HOLE_YSPAN / 2) post();
    txy(gimbal_x + GIMBAL_HOLE_XSPAN / 2, gimbal_y + GIMBAL_HOLE_YSPAN / 2) post();
  }

  module gimbal_mounting_holes() {
    module hole() {
      hole_diameter = 3.5;
      hole_depth = 10;
      tz(gimbal_z - hole_depth) cylinder(d=hole_diameter, h=hole_depth + overlap);
    }
    txy(gimbal_x - GIMBAL_HOLE_XSPAN / 2, gimbal_y - GIMBAL_HOLE_YSPAN / 2) hole();
    txy(gimbal_x + GIMBAL_HOLE_XSPAN / 2, gimbal_y - GIMBAL_HOLE_YSPAN / 2) hole();
    txy(gimbal_x - GIMBAL_HOLE_XSPAN / 2, gimbal_y + GIMBAL_HOLE_YSPAN / 2) hole();
    txy(gimbal_x + GIMBAL_HOLE_XSPAN / 2, gimbal_y + GIMBAL_HOLE_YSPAN / 2) hole();
  }

  module motor_pin_port() {
    port_x = pcb_x + 66;
    port_z = pcb_z + 2.2;
    port_xsize = 13;
    port_zsize = 5;
    translate([
        port_x,
        controller_ysize - wall_thickness - overlap,
        port_z]) cube([
          port_xsize,
          wall_thickness + overlap * 2,
          port_zsize]);
  }

  module xt60_port() {
    port_x = pcb_x + 100;
    port_xsize = 15.7;
    port_zsize = 8.3;
    port_z = 10;
    hole_span = 20.5;
    translate([
        port_x - port_xsize / 2,
        controller_ysize - wall_thickness - overlap,
        port_z - port_zsize / 2]) cube([
          port_xsize,
          wall_thickness + overlap * 2,
          port_zsize]);
    module hole() {
      hole_size = 2.5;
      translate([
          port_x,
          controller_ysize - wall_thickness - overlap,
          port_z]) rx(-90) cylinder(d=hole_size, h=wall_thickness + overlap * 2);
    }
    tx(hole_span / 2) hole();
    tx(-hole_span / 2) hole();
  }

  module remote_trigger_port() {
    port_diameter = 4;
    port_x = 64;
    port_z = 10;
    translate([
        port_x,
        controller_ysize - wall_thickness - overlap,
        port_z]) rx(-90) cylinder(d=port_diameter, h=wall_thickness + overlap * 2);
  }

  module usb_port() {
    port_y = pcb_y + 19;
    port_z = pcb_z + 5.5;
    port_ysize = 16;
    port_zsize = 10;
    translate([
        controller_xsize - wall_thickness - overlap,
        port_y - port_ysize / 2,
        port_z - port_zsize / 2]) #cube([
          wall_thickness + overlap * 2,
          port_ysize,
          port_zsize]);
  }

  color("#700") difference() {
    union() {
      difference() {
        controller_slice(0, zsize);
        tz(controller_base_thickness) controller_slice(wall_thickness, zsize);
      }
      top_plate_mounting_posts();
      pcb_mounts();
      gimbal_mounting_posts();
    }
    top_place_mouting_holes();
    pcb_mount_holes();
    gimbal_mounting_holes();
    motor_pin_port();
    xt60_port();
    remote_trigger_port();
    usb_port();
  }
}

module cover() {
  cover_thickness = 3;
  port_width = 16;

  module mounting_holes() {
    module hole() {
      hole_diameter = 2.1;
      tz(-overlap) cylinder(d=hole_diameter, h=cover_thickness + overlap * 2);
    }
    for (i=[0:len(plate_mounting_holes)-1]) {
      txy(plate_mounting_holes[i][0], plate_mounting_holes[i][1]) hole();
    }
  }

  module left_buttons_port() {
    port_x = pcb_x + 8.35;
    port_y = pcb_y + 23.1;
    port_span = 25.4;
    module port_end() {
      translate([
          port_x,
          port_y,
          -overlap]) cylinder(d=port_width, h=cover_thickness + overlap * 2);
    }
    hull() {
      ty(-port_span / 2) port_end();
      ty(port_span / 2) port_end();
    }
  }

  module right_button_port() {
    port_x = pcb_x + 56.6;
    port_y = pcb_y + 10.4;
    translate([
        port_x,
        port_y,
        -overlap]) cylinder(d=port_width, h=cover_thickness + overlap * 2);
  }

  module boot_button_port() {
    port_x = pcb_x + 102.95;
    port_y = pcb_y + 22.2;
    boot_port_width = 8;
    translate([
        port_x,
        port_y,
        -overlap]) cylinder(d=boot_port_width, h=cover_thickness + overlap * 2);
  }

  module a9488_port() {
    fillet = 3;
    port_x = pcb_x + 62.45;
    port_y = pcb_y + 34.5;
    port_xsize = 19.8;
    port_ysize = 14.7;
    module corner() {
      translate([
          port_x,
          port_y,
          -overlap]) cylinder(r = fillet, h=cover_thickness + overlap * 2);
    }

    hull() {
      txy(fillet, fillet) corner();
      txy(port_xsize - fillet, fillet) corner();
      txy(port_xsize - fillet, port_ysize - fillet) corner();
      txy(fillet, port_ysize - fillet) corner();
    }
  }

  module gimbal_port() {
    port_diameter = 20;
    translate([
        gimbal_x,
        gimbal_y,
        -overlap]) cylinder(r = port_diameter, h=cover_thickness + overlap * 2);
  }

  color("#ddd", 0.3) tz(controller_zsize) difference() {
    controller_slice(0, cover_thickness);
    mounting_holes();
    left_buttons_port();
    right_button_port();
    boot_button_port();
    a9488_port();
    gimbal_port();
  }
}

module placed_pcb() {
  translate([
      pcb_x,
      pcb_y,
      pcb_z]) pcb();
}
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

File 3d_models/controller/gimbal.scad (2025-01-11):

use <lib/mattwach/util.scad>

GIMBAL_HOLE_XSPAN = 35; 
GIMBAL_HOLE_YSPAN = 42; 

overlap = 0.01;

module gimbal() {
  base_plate_height = 1.5;
  bottom_parts_zsize = 17;
  fit_cylinder_height = 5;
  gimbal_cutout_xsize = 26.3;
  gimbal_cutout_ysize = 18.8;
  gimbal_cylinder_diameter = gimbal_cutout_ysize;
  mount_hole_outer_diameter = 6.7;
  mount_hole_height = 5.4;

  module mount() {
    mount_hole_inner_diameter = 4.5;
    mount_hole_diameter = 2.8;
    mount_hole_top_inset = 1.6;
    mount_hole_bottom_inset = 2.4;

    difference() {
      cylinder(d=mount_hole_outer_diameter, h=mount_hole_height);
      tz(mount_hole_height - mount_hole_top_inset) cylinder(
          d=mount_hole_inner_diameter, h=mount_hole_top_inset + overlap);
      tz(-overlap) cylinder(
          d=mount_hole_inner_diameter,
          h=mount_hole_bottom_inset + overlap);
      cylinder(d=mount_hole_diameter, h=mount_hole_height);
    }
  }

  module mount_hole() {
    mount_hole_diameter = 2.8;
    cylinder(d=mount_hole_diameter, h=mount_hole_height);
  }

  module base_plate() {
    base_plate_inset = 2;
    base_plate_xsize = (
        GIMBAL_HOLE_XSPAN + mount_hole_outer_diameter - base_plate_inset);
    base_plate_ysize = (
        GIMBAL_HOLE_YSPAN + mount_hole_outer_diameter - base_plate_inset);
    txy(-base_plate_xsize / 2, -base_plate_ysize / 2)
      cube([base_plate_xsize, base_plate_ysize, base_plate_height]);
  }

  module fit_cylinder() {
    fit_cylinder_diameter = 37.6;
    tz(base_plate_height - overlap) cylinder(
        d=fit_cylinder_diameter, h=fit_cylinder_height + overlap);
  }

  module bottom_parts() {
    bottom_parts_xsize = 41.2;
    bottom_parts_ysize = 36.3;

    translate([
        -bottom_parts_xsize / 2,
        -bottom_parts_ysize / 2,
        -bottom_parts_zsize]) cube([
          bottom_parts_xsize,
          bottom_parts_ysize,
          bottom_parts_zsize + overlap]);
  }

  module gimbal_cutout() {
    gimbal_cutout_zsize = (bottom_parts_zsize + fit_cylinder_height +
        base_plate_height + overlap * 2);
    translate([
        -gimbal_cutout_xsize / 2,
        -gimbal_cutout_ysize / 2,
        -bottom_parts_zsize - overlap]) cube([
          gimbal_cutout_xsize,
          gimbal_cutout_ysize,
          gimbal_cutout_zsize]);
  }

  module gimbal_cylinder() {
    gimbal_cylinder_length = gimbal_cutout_xsize;
    translate([
        -gimbal_cylinder_length / 2,
        0,
        -gimbal_cylinder_diameter / 2 + base_plate_height + fit_cylinder_height]) ry(90) cylinder(
          d=gimbal_cylinder_diameter, h=gimbal_cylinder_length);
  }

  module gimbal_stick() {
    gimbal_stick_height = gimbal_cylinder_diameter / 2 + 22;
    finger_grip_height = 14.8;
    stick_base_height = gimbal_stick_height - finger_grip_height;
    module stick_base() {
      stick_base_diameter = 4;
      cylinder(
          d=stick_base_diameter,
          h=gimbal_stick_height - finger_grip_height + overlap);
    }
    module finger_grip() {
      finger_grip_diameter = 8;
      tz(gimbal_stick_height - finger_grip_height) cylinder(
          d=finger_grip_diameter,
          h=finger_grip_height);
    }
    stick_base();
    finger_grip();
  }

  color("#777") difference() {
    union() {
      txy(GIMBAL_HOLE_XSPAN / 2, GIMBAL_HOLE_YSPAN / 2) mount();
      txy(GIMBAL_HOLE_XSPAN / 2, -GIMBAL_HOLE_YSPAN / 2) mount();
      txy(-GIMBAL_HOLE_XSPAN / 2, GIMBAL_HOLE_YSPAN / 2) mount();
      txy(-GIMBAL_HOLE_XSPAN / 2, -GIMBAL_HOLE_YSPAN / 2) mount();
      base_plate();
      fit_cylinder();
      bottom_parts();
    }
    txy(GIMBAL_HOLE_XSPAN / 2, GIMBAL_HOLE_YSPAN / 2) mount_hole();
    txy(GIMBAL_HOLE_XSPAN / 2, -GIMBAL_HOLE_YSPAN / 2) mount_hole();
    txy(-GIMBAL_HOLE_XSPAN / 2, GIMBAL_HOLE_YSPAN / 2) mount_hole();
    txy(-GIMBAL_HOLE_XSPAN / 2, -GIMBAL_HOLE_YSPAN / 2) mount_hole();
    gimbal_cutout();
  }
  color("#777") gimbal_cylinder();
  gimbal_stick();
}

/*
$fa=2.0;
$fs=0.5;
gimbal();
*/

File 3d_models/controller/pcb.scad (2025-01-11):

use <lib/mattwach/util.scad>
include <lib/mattwach/vitamins/electronics/pi_pico.scad>
include <lib/mattwach/vitamins/electronics/capacitor.scad>
include <lib/mattwach/vitamins/electronics/a4988_carrier.scad>
include <lib/mattwach/vitamins/electronics/oled.scad>
include <lib/NopSCADlib/core.scad>
include <lib/NopSCADlib/vitamins/pin_headers.scad>
include <lib/NopSCADlib/vitamins/buttons.scad>
include <lib/NopSCADlib/vitamins/components.scad>
include <lib/NopSCADlib/vitamins/dip.scad>
include <lib/NopSCADlib/vitamins/axials.scad> 
include <lib/NopSCADlib/vitamins/radials.scad> 


PCB_XSIZE = 119.4;
PCB_YSIZE = 57.2;
PCB_ZSIZE = 1.6;

module pcb() {
  header_zsize = 2.54;
  pin_spacing = 2.54;

  module board() {
    translate([
        -91.45,
        127,
        0]) import("macro_rail_kicad_PCB.stl");
  }

  module button() {
    translate([
        8.35,
        10.4,
        PCB_ZSIZE]) square_button(button_6mm);
  }

  module pico() {
    offset_x = 90.2;
    offset_y = 10.1;
    module header() {
      translate([
          offset_x,
          offset_y,
          PCB_ZSIZE + header_zsize]) ry(180) pin_header(2p54header, 20, 1);
    }
    header();
    ty(pin_spacing * 7) header();
    translate([
        offset_x + pin_spacing * 10 + 0.1,
        offset_y + pin_spacing * 7.6,
        PCB_ZSIZE + header_zsize]) rz(180) pi_pico();
  }

  module vreg() {
    translate([
        108.5,
        38.15,
        PCB_ZSIZE + 1]) rz(-90) TO220("7805", leads = 3, lead_length = 5);
  }

  module opto() {
    translate([
        54.5,
        36.8,
        PCB_ZSIZE]) rz(90) pdip(6, "OPTO");
  }

  module resistor() {
    translate([
        53.5,
        28,
        PCB_ZSIZE]) ax_res(res1_8, 100);
  }

  module gimbal_header() {
    translate([
        95.2,
        3.2,
        PCB_ZSIZE]) jst_xh_header(jst_xh_header, 4);
  }

  module motor_header() {
    translate([
        72.4,
        53.4,
        PCB_ZSIZE]) rz(180) pin_header(2p54header, 4, 1, right_angle = true);
  }

  module power_header() {
    translate([
        106.65,
        47.6,
        PCB_ZSIZE]) rz(180) pin_header(2p54header, 2, 1, right_angle = true);
  }

  module opto_header() {
    translate([
        55.85,
        44.6,
        PCB_ZSIZE]) rz(180) pin_header(2p54header, 2, 1, right_angle = true);
  }

  module power_cap() {
    translate([
        91.5,
        48.3,
        PCB_ZSIZE + 4.3]) rx(90) ry(90) rd_electrolytic(ECAP8x11, "470uF16V");
  }

  module smoothing_cap() {
    translate([
        86.3,
        33.5,
        PCB_ZSIZE]) ceramic_capacitor();
  }

  module a4988() {
    translate([
        81.25,
        48.2,
        PCB_ZSIZE + header_zsize]) rz(180) a4988_carrier();
  }

  module oled() {
    translate([
        15.6,
        5.2,
        PCB_ZSIZE + header_zsize]) oled_128x128_1_5in_spi();
  }

  board();
  pico();
  button();
  ty(pin_spacing * 5) button();
  ty(pin_spacing * 10) button();
  tx(pin_spacing * 19) button();
  vreg();
  opto();
  resistor();
  gimbal_header();
  motor_header();
  power_header();
  opto_header();
  power_cap();
  smoothing_cap();
  ty(6.2) smoothing_cap();
  a4988();
  oled();
}

/*
$fa=2.0;
$fs=0.5;
pcb();
*/

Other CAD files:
macro_rail_kicad/export/macro_rail_kicad.step
3d_models/motor_mount/flange.scad
3d_models/motor_mount/focus_rail.scad
3d_models/motor_mount/foot.scad
3d_models/motor_mount/knob.scad
3d_models/motor_mount/motor.scad
3d_models/motor_mount/motor_bracket.scad
3d_models/motor_mount/motor_mount.scad

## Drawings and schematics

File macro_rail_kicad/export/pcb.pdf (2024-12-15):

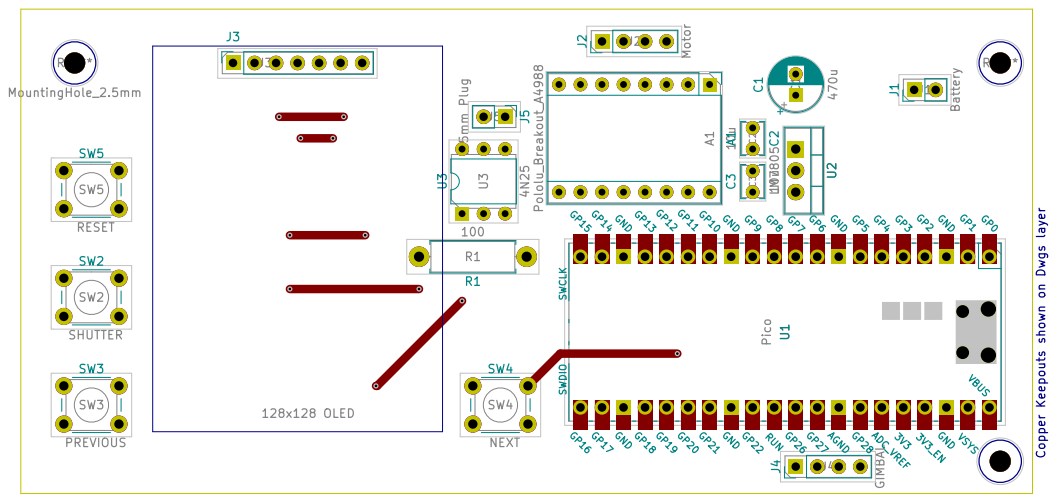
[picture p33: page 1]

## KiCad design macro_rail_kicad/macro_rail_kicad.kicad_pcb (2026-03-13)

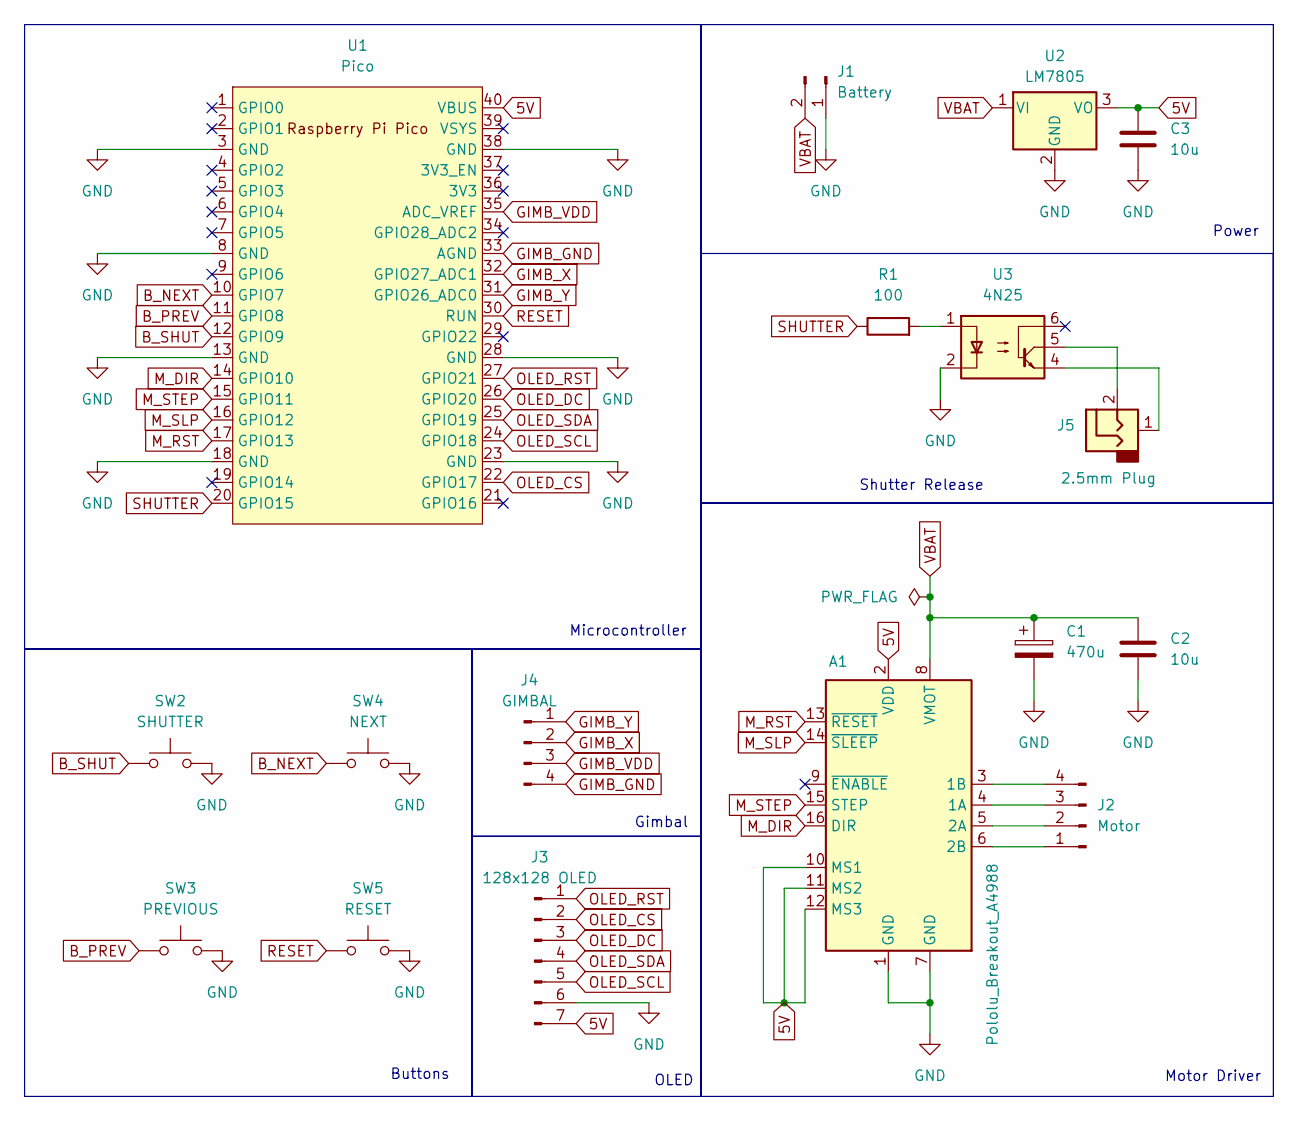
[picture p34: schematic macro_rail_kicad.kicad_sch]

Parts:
A1: Pololu_Breakout_A4988; Pololu_Breakout-16_15.2x20.3mm
C1: 470u; CP_Radial_D6.3mm_P2.50mm
C2, C3: 10u; C_Disc_D3.8mm_W2.6mm_P2.50mm
J1: Battery; PinHeader_1x02_P2.54mm_Vertical
J2: Motor; PinHeader_1x04_P2.54mm_Vertical
J3: 128x128 OLED; OLED_128_128_1.5in
J4: GIMBAL; PinHeader_1x04_P2.54mm_Vertical
J5: 2.5mm Plug; PinHeader_1x02_P2.54mm_Vertical
R1: 100; R_Axial_DIN0411_L9.9mm_D3.6mm_P12.70mm_Horizontal
SW2: SHUTTER; SW_PUSH_6mm_H4.3mm
SW3: PREVIOUS; SW_PUSH_6mm_H4.3mm
SW4: NEXT; SW_PUSH_6mm_H4.3mm
SW5: RESET; SW_PUSH_6mm_H4.3mm
U1: Pico; RPi_Pico_SMD_TH
U2: LM7805; TO-220-3_Vertical
U3: 4N25; DIP-6_W7.62mm

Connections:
5V: A1.2 (VDD), A1.10 (MS1), A1.11 (MS2), A1.12 (MS3), C3.1, J3.7, U1.40 (VBUS), U2.3 (VO)
B_NEXT: SW4.1, U1.10 (GPIO7)
B_PREV: SW3.1, U1.11 (GPIO8)
B_SHUT: SW2.1, U1.12 (GPIO9)
GIMB_GND: J4.4, U1.33 (AGND)
GIMB_VDD: J4.3, U1.35 (ADC_VREF)
GIMB_X: J4.2, U1.32 (GPIO27_ADC1)
GIMB_Y: J4.1, U1.31 (GPIO26_ADC0)
GND: A1.1 (GND), A1.7 (GND), C1.2, C2.2, C3.2, J1.1, J3.6, SW2.2, SW3.2, SW4.2, SW5.2, U1.3 (GND), U1.8 (GND), U1.13 (GND), U1.18 (GND), U1.23 (GND), U1.28 (GND), U1.38 (GND), U2.2 (GND), U3.2
M_DIR: A1.16 (DIR), U1.14 (GPIO10)
M_RST: A1.13 (~RESET), U1.17 (GPIO13)
M_SLP: A1.14 (~SLEEP), U1.16 (GPIO12)
M_STEP: A1.15 (STEP), U1.15 (GPIO11)
unnamed: A1.4 (1A), J2.3
unnamed: A1.3 (1B), J2.4
unnamed: A1.5 (2A), J2.2
unnamed: A1.6 (2B), J2.1
unnamed: J5.1, U3.4
unnamed: J5.2, U3.5
unnamed: R1.2, U3.1
OLED_CS: J3.2, U1.22 (GPIO17)
OLED_DC: J3.3, U1.26 (GPIO20)
OLED_RST: J3.1, U1.27 (GPIO21)
OLED_SCL: J3.5, U1.24 (GPIO18)
OLED_SDA: J3.4, U1.25 (GPIO19)
RESET: SW5.1, U1.30 (RUN)
SHUTTER: R1.1, U1.20 (GPIO15)
VBAT: A1.8 (VMOT), C1.1, C2.1, J1.2, U2.1 (VI)

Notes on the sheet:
Buttons
Shutter Release
Power
Gimbal
Motor Driver
Microcontroller
OLED

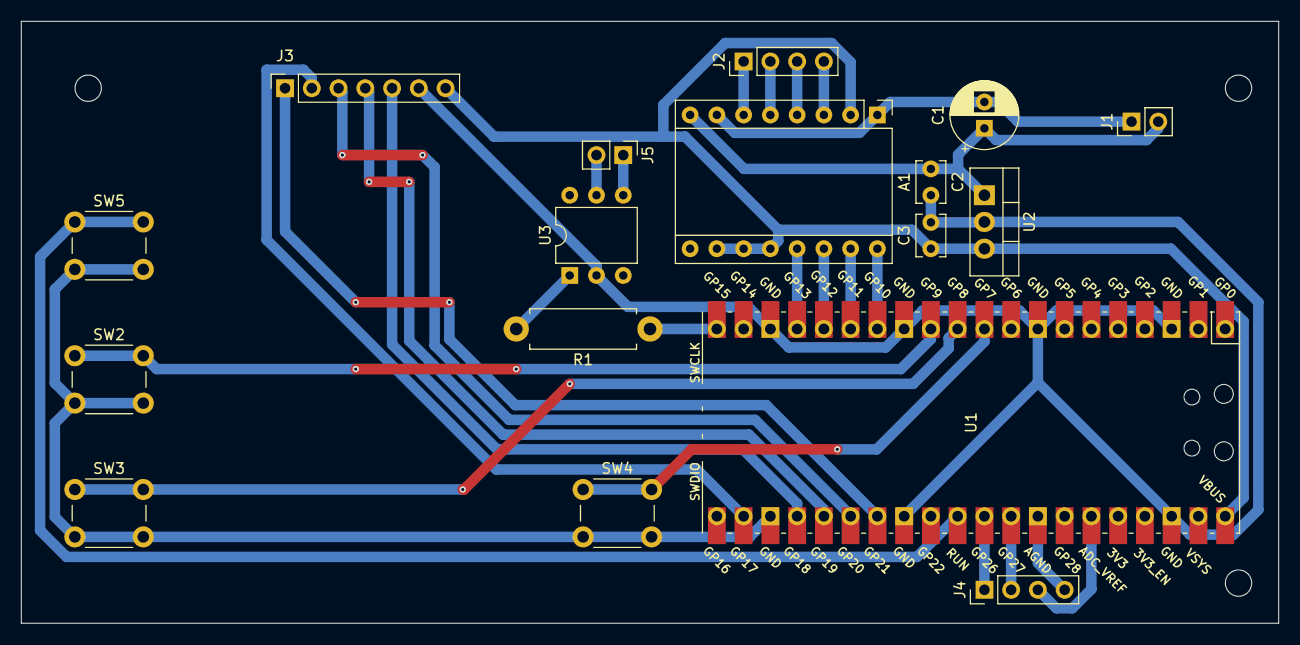
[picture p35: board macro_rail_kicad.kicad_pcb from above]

Board: 2 copper layers, 119.4 x 57.2 mm, 17 parts (0 on the bottom side), 28 nets.

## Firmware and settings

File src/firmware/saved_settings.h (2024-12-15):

// Contains program settings, stored in flash
#ifndef SAVED_SETTINGS_H
#define SAVED_SETTINGS_H

// This module handles settings.  It handles both the user interface
// (shell prompt over USB) and storing/loading from flash.

#include <inttypes.h>
#include "shared_state.h"

//Change this when adding fields.  It will cause all settings to reset
#define SAVED_SETTINGS_VERSION 1

// defaults
#define DEFAULT_MAX_VELOCITY 4800
#define DEFAULT_ACCELERATION 4800
#define DEFAULT_BACKLASH 25
#define DEFAULT_SETTLE_DSECS 10
#define DEFAULT_STEPS_PER_MM 3200

// Here are the settings.  The checksum, eyecatcher and version fields
// are there to detect the cases where setting have not ever been written
// or were updated in an incompatible way.  Bad/unreliable flash could also
// cause mismatches here. Having the eyscatcher is probably caution overkill
// but it can help in troubleshooting efforts.
struct SavedSettings {
  uint32_t checksum;  // the sum of all byte in this structure except for this one
  uint8_t eyecatcher[4];  // 'MARF'
  uint32_t version;  // bump this when structure changes

  int32_t max_velocity;
  int32_t acceleration;
  int32_t backlash;
  int32_t settle_dsecs;  // seconds * 10
  int32_t steps_per_mm;
};

void saved_settings_init(void);

// Get a read-only copy of the settings.
const struct SavedSettings* saved_settings_get(void);

// Update saved settings.  Note this writes to flash which causes wear,
// thus should only be done occasionally.
// This also disables interrupts (as previous usage of flash write have
// deemed this necessary).
void saved_settings_write(
    struct SharedState* state, const struct SavedSettings* ss);

#endif

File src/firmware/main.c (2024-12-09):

#include <pico/stdlib.h>
#include <string.h>

#include <oledm/oledm.h>
#include "shared_state.h"

#include "acceleration.h"
#include "backlash.h"
#include "buttons.h"
#include "end_point_select.h"
#include "gimbal_update.h"
#include "fatal.h"
#include "logging.h"
#include "main_led.h"
#include "max_velocity.h"
#include "menu.h"
#include "run.h"
#include "saved_settings.h"
#include "settle_seconds.h"
#include "shot_count.h"
#include "shutter_delay.h"
#include "shutter.h"
#include "steps_per_mm.h"

// A4988 Stepper Motor Controller (Reference only)
//
//         +------------+
//  N/C 1 -| EN    VMOT |- 16 +12V (with 100uf cap)
//  GND 2 -| MS1    GND |- 15 GND
//  GND 3 -| MS2     2B |- 14 MOTOR
//  GND 4 -| MS3     2A |- 13 MOTOR
// GP10 5 -| RST     1A |- 12 MOTOR
// GP11 6 -| SLP     1B |- 11 MOTOR
// GP12 7 -| STEP   VDD |- 10 +5V
// GP13 8 -| DIR    GND |- 9  GND
//         +------------+
//
// Pi Pico (A4988 pins not yet settled or coded)
//
//             +-------------------------------------+
//          1 -| TX0*/SDA0/MISO0/G0             VBUS |- 40 
//          2 -| RX0*/SCL0/CS0/G1               VSYS |- 39
//          3 -| GND                             GND |- 38
//          4 -| G2/SDA1/SCK0                  3V3EN |- 37
//          5 -| B3/SCL1/MOSI0                   3V3 |- 36
//          6 -| SDA0*/TX1/MISO0/G4             AREF |- 35 GIMBAL_VDD
//          7 -| SCL0*/RX1/CS0/G5           G28/ADC2 |- 34
//          8 -| GND                        AGND/GND |- 33 GIMBAL_GND
//          9 -| G6/SDA1/SCK0          G27/ADC1/SCL1 |- 32 GIMBAL_Y
// B_SHUT  10 -| G7/SCL1/MOSI0         G26/ADC0/SDA1 |- 31 GIMBAL_X
// B_PREV  11 -| G8/TX1/SDA0/MISO1               RUN |- 30 RESET
// B_NEXT  12 -| G9/RX1/SCL0/CS1                 G22 |- 29
//         13 -| GND                             GND |- 28
// M_RST   14 -| G10/SDA1/SCK1              G21/SCL0 |- 27 OLED_RST
// M_SLP   15 -| G11/SCL1/MOSI1             G20/SDA0 |- 26 OLED_DC
// M_STEP  16 -| G12/TX0/SDA0/MISO1  MOSI0*/G19/SCL1 |- 25 OLED_SDA
// M_DIR   17 -| G13/RX0/SCL0/CS1     SCK0*/G18/SDA1 |- 24 OLED_SCL
//         18 -| GND                             GND |- 23
//         19 -| G14/SDA1/SCK1     CS0*/G17/SCL0/RX0 |- 22 OLED_CS
// SHUTTER 20 -| G15/SCL1/MOSI1  MISO0*/G16/SDA0/TX0 |- 21
//             +-------------------------------------+


static struct OLEDM display;
static struct SharedState state;
static uint8_t bitmap_data[DISPLAY_WIDTH * DISPLAY_ROWS];

static void update(void) {
  state.main_led_claimed = 0;
  buttons_update(&state);
  gimbal_update(&state);
  bitmap_fill(&state.bitmap, 0);

  switch (state.state) {
    case STATE_FATAL:
      fatal_update(&state);
      break;
    case STATE_END_POINT_SELECT:
      end_point_select_update(&state, false);
      break;
    case STATE_START_POINT_SELECT:
      end_point_select_update(&state, true);
      break;
    case STATE_SHUTTER_DELAY:
      shutter_delay_update(&state);
      break;
    case STATE_SHOT_COUNT:
      shot_count_update(&state);
      break;
    case STATE_RUNNING:
      run_update(&state);
      break;
    case STATE_MENU:
      menu_update(&state);
      break;
    case STATE_MAX_VELOCITY:
      max_velocity_update(&state);
      break;
    case STATE_ACCELERATION:
      acceleration_update(&state);
      break;
    case STATE_BACKLASH:
      backlash_update(&state);
      break;
    case STATE_SETTLE_SECONDS:
      settle_seconds_update(&state);
      break;
    case STATE_STEPS_PER_MM:
      steps_per_mm_update(&state);
      break;
    default:
      fatal(&state, "UNKNOWN_STATE: %d", state.state);
  }

  logging_update(&state);

  bitmap_render_fast(&display, &state.bitmap, 0, 0); 
  if (!state.main_led_claimed) {
    main_led_put(state.frame_idx & 0x20);
  }
  ++state.frame_idx;
}

static void start_motor_control(void) {
  const struct SavedSettings* settings = saved_settings_get();
  motor_control_init(
      &state.motor,
      settings->backlash,
      settings->max_velocity,
      settings->acceleration);
  motor_control_start_loop(&state.motor);
}


static void init() {
  logging_init();
  sleep_ms(50);
  saved_settings_init();
  main_led_init();

  memset(&state, 0, sizeof(struct SharedState));
  state.state = STATE_END_POINT_SELECT;
  state.bitmap.rows = DISPLAY_ROWS;
  state.bitmap.columns = DISPLAY_WIDTH;
  state.bitmap.data = bitmap_data;

  oledm_basic_init(&display);
  oledm_start(&display);
  oledm_clear(&display, 0x00);

  shutter_init();
  buttons_init();
  shutter_delay_init(&state);
  shot_count_init(&state);
  gimbal_update_init(&state);
  start_motor_control();
}

int main(void) {
  init();

  while (1) {
    update();
    sleep_ms(15);
  }
}

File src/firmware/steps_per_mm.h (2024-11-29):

#ifndef STEPS_PER_MM_H
#define STEPS_PER_MM_H

#include "shared_state.h"

void steps_per_mm_init(const char* title);
void steps_per_mm_update(struct SharedState* ss);

#endif

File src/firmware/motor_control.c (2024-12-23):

#include <string.h>
#include "motor_control.h"
#include "motor_driver.h"
#include <math.h>
#include "pico/multicore.h"

#ifdef TEST
void sleep_us(uint32_t unused) { }
#else
#include "pico/stdlib.h"
#endif

// Run the loop around 10khz
#define LOOP_DELAY_US 50
// sleep after 30 seconds (30,000,000 / LOOP_DELAY_US)
#define IDLE_CYCLES_BEFORE_SLEEP 600000

#define RUNNING_FALSE 0
#define RUNNING_TRUE 1
#define RUNNING_REQUEST_STOP 2

static inline uint8_t near_zero(double v, double threshold) {
  return (v < threshold) && (v > -threshold);
}

static inline void sleep(struct MotorControl* mc) {
  motor_driver_step(0); // always set low if preparing for sleep
  mc->sleep = 1;
}

static inline void prepare(struct MotorControl* mc, int8_t direction) {
  if (mc->sleep) {
    mc->sleep = 0;
    mc->idle_frames = 0;
    motor_driver_wake();
  }
  if (mc->direction != direction) {
    mc->direction = direction;
    motor_driver_dir(direction);
  }
}

void motor_control_init(
    struct MotorControl* mc,
    uint32_t backlash,
    uint32_t max_velocity,
    uint32_t acceleration) {
  memset(mc, 0, sizeof(*mc));
  mc->backlash = backlash;
  mc->max_velocity = max_velocity;
  mc->acceleration = acceleration;
  int lock_num = spin_lock_claim_unused(1);
  mc->lock = spin_lock_init(lock_num);
  motor_driver_init();
  motor_driver_sleep();
  mc->sleep = 1;
  mc->running = RUNNING_FALSE;
}

static double update_physics_normalized(
    double dist, double vel, double acc, double max_vel, double delta_seconds) {
  // first, apply the acceleration normally
  vel += acc * delta_seconds;
  if (vel > max_vel) {
    vel = max_vel;
  }

  // Now check, if we apply maximum deceleration, will we end up going further
  // or shorter than dist.  If it's further, then deccelleration (braking) needs to
  // be applied.
  const double braking_dist = vel * vel / (2.0 * acc);
  if (braking_dist > dist) {
    // undo the overshoot so a proper calculation is not biased.
    vel -= acc * delta_seconds;
    // now add a very small amount of overshoot
    dist += 0.02;
    // here we need to recalculate the needed decelleration so that we hit the target
    // right on.  In otherwords:
    //   dist = vel * vel / (2.0 * newacc)
    //   dist * 2.0 * newacc = vel * vel
    //   newacc = vel * vel / (2.0 * dist)
    // also make it negative
    acc = -(vel * vel / (2.0 * dist));
    vel += acc * delta_seconds;
  }

  return vel;
}

static void update_physics(struct MotorControl* mc, double delta_seconds) {
  // The first task is to remove the offsets and symmetry of the calculation,
  // Removing the offset means we don't have to carry it through calculations
  // and symmetry means that we don't have to do every calculation in positive
  // and negative directions.
  double dist = mc->target_pos - mc->current_pos;
  double velocity = mc->velocity;
  double acceleration = mc->acceleration;
  uint8_t invert = 0;

  if (dist < 0) {
    dist = -dist;
    velocity = -mc->velocity;
    invert = 1;
  }

  if ((dist < 0.1) && near_zero(velocity, 0.1)) {
    // close enough
    return;
  }
  velocity = update_physics_normalized(
    dist,
    velocity,
    acceleration,
    mc->max_velocity,
    delta_seconds);

  if (invert) {
    mc->velocity = -velocity;
  } else {
    mc->velocity = velocity;
  }
}

static void update_current_pos_positive(struct MotorControl* mc) {
  const double new_curr_pos = (mc->motor_pos / 2) - mc->backlash;
  if (new_curr_pos > mc->current_pos) {
    mc->current_pos = new_curr_pos;
  }
}

static void update_current_pos_negative(struct MotorControl* mc) {
  const double new_curr_pos = (mc->motor_pos / 2) + mc->backlash;
  if (new_curr_pos < mc->current_pos) {
    mc->current_pos = new_curr_pos;
  }
}

static void update_current_pos(struct MotorControl* mc) {
  if (mc->velocity > 0) {
    update_current_pos_positive(mc);
  } else if (mc->velocity < 0) {
    update_current_pos_negative(mc);
  }
}

static void update_jog_velocity(struct MotorControl* mc, double delta_seconds) {
  const double max_delta_v = mc->acceleration * delta_seconds;

  if (mc->jog_velocity > mc->velocity) {
    const double delta_v = mc->jog_velocity - mc->velocity;
    if (delta_v < max_delta_v) {
      mc->velocity = mc->jog_velocity;
    } else {
      mc->velocity += max_delta_v;
    }
  } else {
    const double delta_v = mc->velocity - mc->jog_velocity;
    if (delta_v < max_delta_v) {
      mc->velocity = mc->jog_velocity;
    } else {
      mc->velocity -= max_delta_v;
    }
  }
}

void update_position(struct MotorControl* mcp, double delta_seconds) {
  const int32_t orig_motor_pos = (int32_t)(mcp->motor_pos);
  const double new_motor_pos = mcp->motor_pos + (mcp->velocity * delta_seconds);
  const int32_t delta = (int32_t)(new_motor_pos) - orig_motor_pos;

  if (delta > 0) {
    prepare(mcp, 1);
    motor_driver_step((orig_motor_pos + delta) & 1);
  } else if (delta < 0) {
    prepare(mcp, -1);
    motor_driver_step((orig_motor_pos + delta) & 1);
  }

  if ((delta <= 1) && (delta >= -1)) {
    // the usual case
    mcp->motor_pos = new_motor_pos; 
  } else if (delta < 0) {
    // control loop is too slow
    mcp->motor_pos -= 1;
  } else {
    // control loop is too slow
    mcp->motor_pos += 1;
  }
  update_current_pos(mcp);
}

void check_for_jog_end(struct MotorControl* mcp) {
  if (near_zero(mcp->jog_velocity, 0.5) &&
      near_zero(mcp->velocity, 0.5)) {
    mcp->velocity = 0;
    mcp->jog_velocity = 0;
    mcp->jog_mode = 0;
    mcp->current_pos = (int32_t)(mcp->current_pos);
    mcp->target_pos = mcp->current_pos;
    sleep(mcp);
  }
}

void check_for_target_reached(struct MotorControl* mcp) {
  double target_dist = mcp->target_pos - mcp->current_pos;

  if (((target_dist < 0) && (mcp->velocity >= 0)) ||
      ((target_dist > 0) && (mcp->velocity <= 0))) {
    // overshot the target per-design.  Time to stop.
    mcp->velocity = 0;
    mcp->current_pos = mcp->target_pos;
    sleep(mcp);
  }
}

void motor_control_loop(struct MotorControl* mcp) {
  uint32_t prev_us = mcp->loop_us;
  mcp->loop_us = time_us_32(); // new time

  if (prev_us == 0 || (mcp->loop_us <= prev_us)) {
    return;
  }
  const double delta_seconds = (double)(mcp->loop_us - prev_us) / 1000000.0;

  if (mcp->jog_mode) {
    update_jog_velocity(mcp, delta_seconds);
    // *2 allows for appropriate velocity through the unit conversion
    update_position(mcp, delta_seconds * 2);
    check_for_jog_end(mcp);
  } else {
    update_physics(mcp, delta_seconds);
    update_position(mcp, delta_seconds * 2);
    check_for_target_reached(mcp);
  }
}
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

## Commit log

2024-10-27 added basic rail body
    [motor_mount.scad]
2024-10-28 added foot design
    [motor_mount.scad]
2024-10-28 added feet and moved foot to a separate file
    [motor_mount.scad]
2024-10-28 Moved focus_rail and foot to separate files and translated them to put 0,0,0 at a convienient spot.
    [focus_rail.scad, foot.scad, motor_mount.scad]
2024-10-28 Added knob model
    [knob.scad]
2024-10-28 made knob finger part parametric for later cutout
    [focus_rail.scad, knob.scad]
2024-10-28 Positioned knob
    [focus_rail.scad]
2024-10-28 Added motor base.
    [motor.scad, motor_mount.scad]
2024-10-28 Added motor mounting holes
    [motor.scad]
2024-10-28 finished motor vitamin
    [motor.scad]
2024-10-28 Placed motor in main design
    [knob.scad, motor.scad, motor_mount.scad]
2024-11-17 Setup basic framework for state changes.
2024-11-17 Made fatal errors cleaner to create.
    [main.c]
2024-11-17 Added back main led blink which was somehow lost.
2024-11-17 Added more hookup details to comment. Some minor bug fixes.
    [main.c]
2024-11-18 Moved over motor driver sources.
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2024-11-18 Fixed logic bug in new jog code.
    [end_point_select.c, shared_state.h]
2024-11-18 Added backlash meter.
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2024-11-19 Changing the motor driver logic to allow for evenly-space high and low cycle times.
    It's unclear if this is necessary, but every example I can find uses evenly-spaced times.
    This does make the code a bit more complex to understand and may have introduced bugs.
    Some additional validation with the driver emulator and oscilliscope is needed.
    [motor_control.c, motor_driver.c]
2024-11-19 Worked on backlash ui
    [end_point_select.c]
2024-11-19 Fixed even step time logic.
    The only was didn't work as visible on an oscilliscope. The new way
    scales motor pos by 2 and uses the parity to set a high-low.
    This seems to mostly owrk but I now see some step mismatches that
    are minor but perhaps worth looking into more.
    [end_point_select.c, motor_control.c]
2024-11-19 fixed backlash scaling calculation
    [end_point_select.c]
2024-11-19 Removed micro side step, zero after end point
    - microstep didn't work well due to backlash
    - zero afrer end point is a logical time to do it and saves a button
    [end_point_select.c]
2024-11-19 Added framework for shutter delay UI.
    Created render_common.h for common UI functions (render_title, currently).
2024-11-19 refactored end_point_select update and added some support for previous button
2024-11-19 Display bug fixes from previous change.
    [end_point_select.c]
2024-11-19 Only allow delay if start pos is <>1mm
2024-11-20 Fixed minor rendering and cal bugs from last commit.
    [end_point_select.c, shot_count.c]
2024-11-20 Fixed some issues on post code review.
    [buttons.c, end_point_select.c, main.c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]
2024-11-21 Fixed various minor bugs.
    Fixed shutter GPIO number.
    Stop elasped time at end of shoot.
    Fix reverrse calculation (casting was needed).
    [motor_control.c, run.c]
2024-11-21 Added motor seek calculation for better overall time calculation.
    The math is a bit tricky so it might need some revs.
2024-11-22 Added flange
    [flange.scad, knob.scad, motor.scad]
2024-11-22 Added motor bracket.
    [flange.scad, focus_rail.scad, motor_bracket.scad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]
2024-11-23 Fixed the non-centered knob issue.
    [focus_rail.scad, motor_bracket.scad, motor_mount.scad]
2024-11-23 Started kicad schematic.
    [macro_rail_kicad.kicad_pcb, macro_rail_kicad.kicad_sch]
2024-11-28 Incorporate saved settings into max velocity parmeter ui.
2024-11-28 Added backlash parameter change.
    [backlash.c, main.c, shared_state.h]
2024-11-29 Organized schematic.
    [macro_rail_kicad.kicad_sch]
2024-11-29 Added optocoupler and cleaned up ERC errors.
    [macro_rail_kicad.kicad_sch]
2024-11-30 Fxied some footpring issues annd imported initial netlist into pcb.
    [macro_rail_kicad.kicad_pcb, macro_rail_kicad.kicad_sch]
2024-11-30 Finished draft of PCB
    [macro_rail_kicad.kicad_pcb, macro_rail_kicad.kicad_sch]
2024-11-30 Added mounting holes. Fixed DRC violations.
    [macro_rail_kicad.kicad_pcb]
2024-12-02 Schematic tidying
    [macro_rail_kicad.kicad_sch]
2024-12-04 README links updates. Removed power switch (amps too low)
    [macro_rail_kicad.kicad_pcb, macro_rail_kicad.kicad_sch]
2024-12-05 Added stl models and README updates.
    [ns200_flange.stl, ns200_motor_mount.stl]
2024-12-09 Fixed sign issue that broke the jogging code (during a refactor)
    [gimbal_jog.c]
2024-12-09 Fixed polarity of manual shutter delay.
    [run.c]
2024-12-09 Hopefully fixed test bug for max veliocity
    [max_velocity.c]
2024-12-09 Disable CPU1 during flash write.
    Looking at an old project I see this was done and remember debugging
    the issue in the past. It makes sence that writing flash needs
    a very quiet environment to work properly.
    With this, I likely don't need the debug stuff I added earlier, but
    I'll keep in it place until I see eveything working as expected.
    [main.c, motor_control.c, parameter_change.c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]
2024-12-09 motor_control_stop -> motor_control_stop_loop
    Noticed this while reviewing the codee diff. emoved the old functin sig
    to avoid future confusing over its ambiguous name.
    [motor_control.c, saved_settings.c]
2024-12-11 Fixed logging bugs. Fixed saved_settings checksum bug.
    [saved_settings.c]
2024-12-12 Fixed bugs in acceleration ui
    [acceleration.c]
2024-12-12 Fixed bugs in backlash ui
    [backlash.c]
2024-12-12 Fixed bugs in settle_seconds ui
    [settle_seconds.c]
2024-12-12 Fixed bugs in steps_per_mm ui
    [steps_per_mm.c]
2024-12-13 fixed backlash test movemnt bug
    [backlash.c]
2024-12-13 fixed settle seconds test bugs
    [backlash.c, settle_seconds.c]
2024-12-13 Possibly corrected steps_per_mm calculations in shot_count.
    It was getting late so I decided not to test until tomorrow.
    [shot_count.c, steps_per_mm.c]
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2024-12-14 Fixed shot suggest calculation
    [shot_count.c]
2024-12-15 Added pcb exports.
    [macro_rail_kicad.kicad_pcb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]
2024-12-15 Changed firmware to use microstepping.
    The sleep need to be delayed to avoid motor snap on wake issues which
    are especially problematic during shooting. Right now
    I'm using a 10 second delay, but it should be made smarter.
    [acceleration.c, max_velocity.c, motor_control.c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]
2024-12-15 Updated schmatic and pcb for microstepping
    [macro_rail_kicad.kicad_pcb, macro_rail_kicad.kicad_sch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]
2024-12-15 removed a4988 calibration because it was not working
    [main.c, shared_state.h]
2024-12-15 Added details on the rail and motor calibration.
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2024-12-15 Reorganized 3d models
    [flange.scad, focus_rail.scad, foot.scad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]
2024-12-15 Started on controller, added gimbal vitamin.
    [controller.scad, gimbal.scad]
2024-12-17 Updated GPIO asssignments to match schematic.
    GPIOs were moved around during the PBC layout to make the layout easier.
2024-12-18 Started PCB model for controller
    [macro_rail_kicad.step, macro_rail_kicad_PCB.stl, pcb.scad]
2024-12-18 Added Pico to PCB
    [pcb.scad]
2024-12-18 Added VREG
    [pcb.scad]
2024-12-18 Added optocoupler
    [pcb.scad]
2024-12-18 Added gimbal header
    [pcb.scad]
2024-12-18 Added pin headers
    [pcb.scad]
2024-12-18 Added caps and a4988.
    [pcb.scad]
2024-12-18 Added images for assembled pcb and cut pcb.
2024-12-18 Added oled.
    [pcb.scad]
2024-12-19 Started shaping controller.
    [controller.scad, gimbal.scad, pcb.scad]
2024-12-19 Controller base now wraps around components.
    [controller.scad]
2024-12-19 tweaking case dimensions
    [controller.scad]
2024-12-19 tweaking case fillet
    [controller.scad]
2024-12-20 Added mounting posts.
    [controller.scad]
2024-12-20 added open_view parameter
    [controller.scad]
2024-12-20 Added PCB mounting posts.
    [controller.scad]
2024-12-20 Thinned controller walls
    [controller.scad]
2024-12-20 Switched top plate bolts to M2.
    The 2.5mm plug can not handle thick walls.
    [controller.scad]
2024-12-20 Added gimbal mounting posts
    [controller.scad]
2024-12-20 added motor port
    [controller.scad]
2024-12-20 added remote trigger portw
    [controller.scad]
2024-12-20 Added cover and cover mount holes
    [controller.scad]
2024-12-20 boot port
    [controller.scad]
2024-12-20 added a4988 port
    [controller.scad]
2024-12-20 added gimbal port
    [controller.scad]
2024-12-20 usb port
    [controller.scad]
2024-12-20 added xt-60 port
    [controller.scad]
2024-12-20 Added exports for controller stl and cover dxf
    [controller.scad, controller.stl, controller_cover.dxf]
2024-12-20 added controller png
    [controller.scad]
2024-12-21 Added docs on the controller casing.
    [controller.scad]
2024-12-22 raied motor port by 1.5mm
    [controller.scad]
2024-12-23 Increased spindle speed.
    If I recall correctly, my CNC needs 10k for full speed.
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2024-12-23 Changed floats to doubles.
    It turns out that floats do not have suffifient precision to span beyond 10.4 mm or so.
    The result is that the moo can not find it's stopping point and the system appears
    to hang and do nothing. Changing to double will give us plenty of range
    for the future.
2025-01-11 Converted OpenSCAD models to be stand-alone
    [controller.scad, flange.scad, focus_rail.scad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]
2026-03-13 Added remaining gerber export files so they can be sent to a fab.
    [macro_rail_kicad-B_Adhesive.gbr, macro_rail_kicad-B_Courtyard.gbr, macro_rail_kicad-B_Cu.gbr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]
